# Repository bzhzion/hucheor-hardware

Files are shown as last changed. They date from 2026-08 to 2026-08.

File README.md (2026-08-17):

# Hucheor Hardware

Matériel et firmware pour **Hucheor**, une balise sonore pour les commerces de proximité qui
répond à la télécommande normalisée française utilisée par les personnes aveugles et malvoyantes
(NF S32-002, 868,3 MHz).

"Hucheor" est un mot de vieux français pour "celui qui appelle, qui guide".

Ce dépôt contient tout ce qui est destiné à être librement partagé et auto-constructible :

- `firmware/` : firmware ESP32 (décodage radio, lecture audio, configuration WiFi)
- `hardware/` : schémas KiCad et fichiers Gerber du circuit imprimé
- `enclosure/` : fichiers d'impression 3D du boîtier (STL)
- `docs/` : captures d'écran et maquettes HTML autonomes de l'interface de configuration (pour
  prévisualiser/tester les pages web sans flasher de matériel réel, voir
  [Interface de configuration](#interface-de-configuration) plus bas)

Le projet global (contexte métier, déploiement, site web) vit dans un dépôt privé séparé. Celui-ci
est la partie publique, en accès libre : n'importe qui peut consulter ces fichiers, les étudier, et
construire un exemplaire pour son usage strictement personnel. Voir [NOTICE.md](NOTICE.md) pour ce
que ça permet exactement (et ce que ça ne permet pas) : ce n'est **pas** une licence open source au
sens OSI, et la fabrication pour un tiers (même gratuite, même associative) est exclue.

## État

**Firmware v1 en développement actif.** L'essentiel de la partie logicielle qui ne dépend pas
d'avoir du matériel physique en main est implémenté et testé (lecture audio, planification,
synchronisation de l'horloge, réseau, interface de configuration, CI). Ce qui manque encore : le
décodage radio NF S32-002 lui-même (bloqué sur la capture d'un signal réel, voir
[Approche](#approche)) et le prototype physique lui-même.

| Domaine | État |
|---|---|
| Réception radio (CC1101 @ 868,3 MHz) | Initialisation + capture brute des fronts uniquement. La reconnaissance de trame (`matchesNfS32002Frame()`) renvoie toujours `false` pour l'instant : volontairement laissé non implémenté tant qu'une vraie capture RTL-SDR n'est pas disponible, voir plus bas. |
| Lecture audio | Fait. WAV (16 bits mono/stéréo) depuis LittleFS via I2S, voir [Lecture audio](#lecture-audio). |
| Planification des horaires d'ouverture | Fait. Modèles saisonniers + plages de semaines, voir [Planification](#planification-horaires-saisonniers). |
| Synchronisation de l'horloge | Fait. Trois sources indépendantes (DCF77, téléphone, NTP), voir [Synchronisation de l'horloge](#synchronisation-de-lhorloge). |
| Réseau (modes point d'accès / station) | Fait. Repli automatique, mDNS, serveur NTP configurable, voir [Modes réseau](#modes-réseau). |
| Interface web de configuration | Fait. Voir [Interface de configuration](#interface-de-configuration). |
| Sécurité | Audité, correctifs appliqués, voir [Sécurité](#sécurité). |
| CI | Build du firmware à chaque push + vérification hebdomadaire des dépendances, voir [Intégration continue](#intégration-continue). |
| Matériel / boîtier | Pas commencé, en attente d'un prototype firmware validé d'abord. |

## Comment ça marche

1. Une personne aveugle ou malvoyante a sur elle la télécommande NF S32-002 déjà distribuée à
   l'échelle nationale (la même que celle utilisée pour les feux piétons sonores et les bâtiments
   publics). Rien de nouveau à transporter.
2. Elle la pointe vers un commerce équipé d'une balise Hucheor et appuie sur le bouton, exactement
   comme elle le ferait devant la balise sonore d'un bâtiment public.
3. La balise (ESP32 + module radio CC1101) capte le signal 868,3 MHz, le reconnaît comme une trame
   NF S32-002, et lit les horaires d'ouverture configurés du commerce pour l'instant présent.
4. Elle diffuse un court message enregistré sur un haut-parleur (ampli I2S MAX98357A) : le nom du
   commerce, et s'il est actuellement ouvert ou fermé.

Aucune application, aucun smartphone requis pour l'usage principal : la télécommande existante est
toute l'interface. Voir la [Feuille de route](#feuille-de-route) pour ce qu'une future application
compagnon ajouterait en plus.

## Lecture audio

`firmware/src/audio_player.{h,cpp}`. Joue des fichiers WAV 16 bits (mono ou stéréo, n'importe
quelle fréquence d'échantillonnage) stockés sur le système de fichiers LittleFS interne de l'ESP32,
via I2S. Le commerçant envoie deux fichiers WAV via l'interface de configuration : un joué quand le
commerce est ouvert, un quand il est fermé (voir
[Interface de configuration](#interface-de-configuration)). Si aucun des deux n'a jamais été
envoyé (ou si les horaires n'ont jamais été configurés), le firmware se rabat sur un
`/message.wav` générique unique plutôt que de rester silencieux.

Le parseur WAV analyse les chunks au lieu de supposer un en-tête fixe de 44 octets (gère les
fichiers avec des chunks `LIST`/`fact` supplémentaires avant `data`), et est durci contre les
fichiers malformés (voir [Sécurité](#sécurité)).

Aucune bibliothèque audio tierce n'est utilisée : le choix évident, ESP8266Audio, est sous licence
GPLv3, ce qui forcerait tout ce dépôt sous une licence copyleft incompatible avec
[la licence ci-dessous](#licence). Le parsing WAV et la lecture I2S sont implémentés directement
au-dessus du `driver/i2s.h` natif du core Arduino ESP32.

## Planification (horaires saisonniers)

`firmware/src/schedule.{h,cpp}`. Les horaires d'ouverture d'un commerce sont rarement les mêmes
toute l'année (horaires d'été, fermeture de Noël, etc.), donc la planification est construite
autour de **modèles**, pas d'un horaire hebdomadaire fixe unique :

- Jusqu'à **4 modèles nommés** (ex. "Standard", "Été", "Vacances de Noël"), chacun un horaire
  hebdomadaire complet sur 7 jours (activé/désactivé par jour, heure d'ouverture, heure de
  fermeture). Un jour peut aussi être une plage nocturne (ferme après minuit, ex. un bar ouvert de
  20h à 2h) : le firmware le détecte automatiquement quand l'heure de fermeture est antérieure à
  l'heure d'ouverture.
- Jusqu'à **12 plages de numéros de semaine ISO** (1-53), chacune assignée à l'un des 4 modèles.
  Une semaine sans plage correspondante se rabat sur le premier modèle. Exemple : semaines 1 à 26
  utilisent "Standard", semaines 27 à 35 utilisent "Été", semaines 36 à 53 utilisent "Standard" à
  nouveau.

Tout ça se modifie depuis le navigateur du téléphone via l'[interface de
configuration](#interface-de-configuration), pas besoin de reflasher pour changer les horaires.

**Sécurité par défaut** : juste après un démarrage à froid ou une coupure de courant, avant qu'une
source d'heure n'ait synchronisé, l'horloge système affiche une valeur proche de zéro
(1970-01-01). `isOpenNow()` refuse de répondre dans ce cas et annonce "fermé" plutôt que de deviner
avec assurance un statut arbitraire à partir d'une date bidon : "fermé" est la mauvaise réponse la
moins grave pour un visiteur aveugle que "ouvert".

## Synchronisation de l'horloge

Le firmware ne calcule jamais lui-même l'heure d'été/d'hiver (CET/CEST). Chaque source d'horloge
est responsable de résoudre le changement d'heure de son côté et de transmettre **l'heure locale
française de l'horloge murale**, encodée comme si c'était de l'UTC : `Schedule` la relit toujours
avec `gmtime_r()`, jamais `localtime_r()`, donc aucune règle de changement d'heure européenne n'est
codée en dur nulle part dans ce firmware (une règle qui pourrait changer : il y a eu de vraies
discussions européennes sur l'abolition pure et simple du changement d'heure saisonnier).

Trois sources indépendantes, n'importe quelle combinaison d'entre elles peut être présente :

- **DCF77** (`firmware/src/dcf77_clock.{h,cpp}`) : un module récepteur grandes ondes 77,5 kHz
  optionnel. Décode le signal horaire allemand DCF77 (également reçu partout en France), qui
  diffuse déjà l'heure locale équivalente française plus des drapeaux CEST/CET en direct : aucune
  conversion nécessaire, fonctionne sans aucune connexion internet.
- **Synchronisation par téléphone** : visiter l'interface de configuration (n'importe quelle page)
  envoie les champs de l'horloge murale locale du téléphone qui configure (déjà ajustés pour le
  changement d'heure par la base de données de fuseaux horaires du système d'exploitation,
  régulièrement mise à jour) à la balise, via un petit script inline.
- **NTP** : disponible uniquement en [mode station](#modes-réseau) (accès internet). Un serveur NTP
  configurable (par défaut `fr.pool.ntp.org`) fournit l'UTC vrai, que le firmware convertit en
  heure locale française exactement une fois par synchronisation (une règle `TZ` transitoire
  appliquée puis immédiatement retirée : jamais laissée configurée en permanence) et se
  resynchronise automatiquement toutes les 6 heures pour corriger la dérive de l'horloge.

## Modes réseau

`firmware/src/network.{h,cpp}`. Deux modes de connexion, permutables depuis la page `/wifi` de
l'interface de configuration :

- **Autonome (par défaut)** : la balise crée son propre point d'accès WiFi (`Hucheor-XXXX`, WPA2,
  un mot de passe généré une fois par appareil). Pas d'accès internet : s'appuie sur DCF77 et/ou la
  synchronisation par téléphone pour l'heure.
- **Station** : la balise rejoint plutôt le réseau WiFi propre du commerce. Plus facile à
  atteindre pour la configuration (le téléphone reste sur son réseau habituel), découvrable via
  mDNS (`hucheor-xxxx.local`, aucune dépendance supplémentaire : `ESPmDNS` est fourni avec le core
  Arduino ESP32), et obtient une synchronisation NTP automatique de l'heure puisqu'elle a
  désormais accès à internet.

Se rabat automatiquement sur le mode autonome si des identifiants station sont configurés mais que
la connexion échoue (mauvais mot de passe, WiFi du commerce en panne, hors de portée) : une erreur
de configuration ne peut jamais rendre l'appareil inaccessible.

Non bloquant et résilient par conception : une connexion station perdue est retentée
automatiquement (délai de 30s entre tentatives, ne sature jamais la radio), et les resynchronisations
NTP se font en arrière-plan sans jamais bloquer la réception radio ou la lecture audio. La seule
attente volontairement bloquante est la tentative de connexion WiFi initiale au démarrage
(jusqu'à 15s, avant que quoi que ce soit d'autre n'ait démarré).

## Interface de configuration

`firmware/src/config_server.{h,cpp}`. Un petit serveur HTTP embarqué (aucune ressource externe,
fonctionne entièrement hors ligne sur le point d'accès autonome) pour que le commerçant configure
la balise depuis le navigateur de n'importe quel téléphone : aucune application requise pour la
configuration. Protégé par HTTP Digest Auth (un code à 12 chiffres, généré une fois par appareil,
jamais envoyé en clair sur le réseau : voir [Sécurité](#sécurité)). Le pied de page de chaque page
affiche la version du firmware en cours d'exécution (voir [Versionnage](#versionnage)).

| Page | À quoi ça sert |
|---|---|
| `/` | Envoyer les messages WAV "ouvert" et "fermé" (2 Mo max chacun). |
| `/schedule` | Modifier les modèles d'horaires d'ouverture et leur assigner des plages de semaines, voir [Planification](#planification-horaires-saisonniers). |
| `/wifi` | Basculer entre mode autonome/station, définir les identifiants WiFi du commerce, configurer le serveur NTP. |

Captures d'écran (générées à partir des maquettes autonomes dans
[`docs/mockups/`](docs/mockups/), qui reproduisent le HTML réellement généré par le firmware
au caractère près : utiles pour prévisualiser un changement d'interface sans flasher un appareil
réel) :

<table>
<tr>
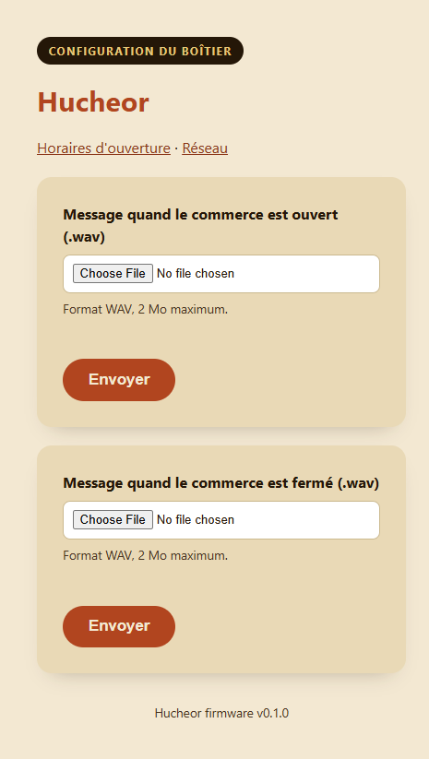
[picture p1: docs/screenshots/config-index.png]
Interface de configuration : page d'accueil avec les deux formulaires d'envoi WAV
<td></td>
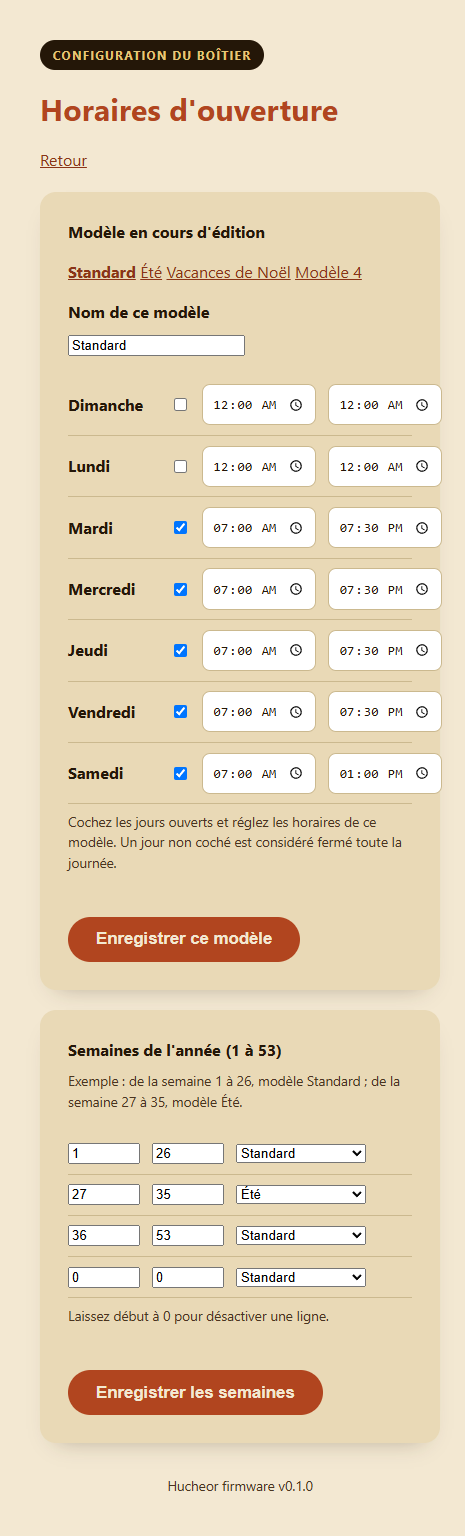
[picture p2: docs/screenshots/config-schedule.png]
Interface de configuration : éditeur des horaires d'ouverture
<td></td>
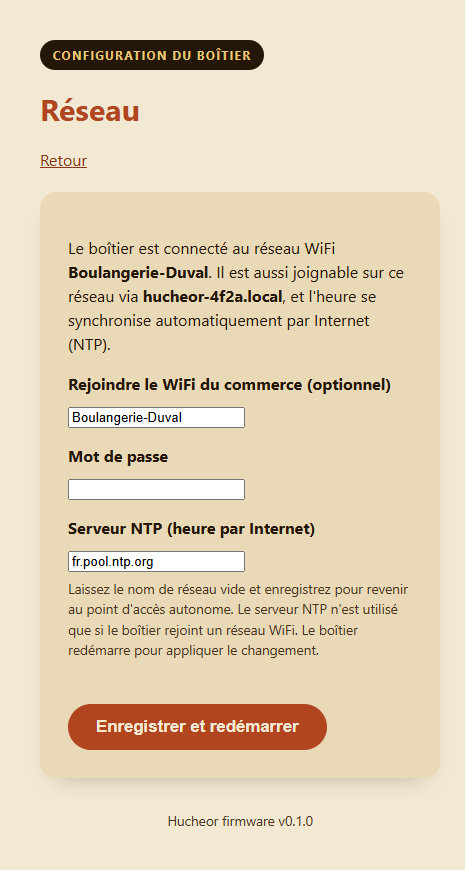
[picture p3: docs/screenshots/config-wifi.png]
Interface de configuration : page des paramètres réseau
<td></td>
</tr>
</table>

Même thème visuel que le site public ("Le Héraut" : parchemin/encre/terracotta), une pile de
polices système à la place des polices web personnalisées du site (inaccessibles depuis un point
d'accès hors ligne sans internet), et construit pour être utilisable : de vrais `<label>`, de
grandes cibles tactiles, des contours de focus visibles, aucun JavaScript en dehors du petit
script inline de synchronisation d'horloge.

### Parcours de première configuration

1. Flasher le firmware (voir [Compiler le firmware](#compiler-le-firmware)).
2. Allumer la balise. Elle démarre en mode autonome, en créant un réseau WiFi nommé
   `Hucheor-XXXX` (le suffixe exact vient de l'adresse MAC de l'appareil, affiché sur la console
   série au démarrage aux côtés des mots de passe WPA2 et de configuration).
3. Sur un téléphone, rejoindre ce réseau WiFi et ouvrir `http://hucheor-xxxx.local` (ou l'IP du
   point d'accès, `192.168.4.1`) dans un navigateur.
4. Se connecter avec les identifiants HTTP Digest affichés sur la console série au démarrage.
5. Envoyer les messages WAV "ouvert" et "fermé" sur la page d'accueil.
6. Aller sur **Horaires d'ouverture** et configurer au moins les horaires hebdomadaires du modèle
   "Standard". Ajouter des modèles saisonniers et des plages de semaines si besoin.
7. Optionnellement, aller sur **Réseau** et saisir les identifiants WiFi du commerce pour basculer
   en mode station (recommandé une fois la configuration faite : synchronisation automatique de
   l'heure par internet et accessibilité au quotidien plus simple via `hucheor-xxxx.local`).
8. Terminé : la balise répond désormais à toute télécommande NF S32-002 à portée.

## Sécurité

Audité selon une checklist adaptée à ce contexte embarqué ESP32 (pas un backend web classique),
centrée sur les deux nouvelles surfaces d'attaque : le serveur de configuration (traite des envois
et des identifiants non fiables) et le parseur WAV (traite du contenu de fichier non fiable).

**Corrigé :**
- Underflow entier dans le parseur du chunk `fmt ` d'un WAV (une taille de chunk malformée
  inférieure à 16 octets débordait en arithmétique non signée vers un offset `seek()` énorme) :
  désormais rejeté explicitement.
- La valeur de retour de `seek()` n'était jamais vérifiée, ce qui pouvait laisser un fichier WAV
  malformé faire tourner la boucle du parseur indéfiniment (déni de service) : interrompt
  désormais le parsing au moindre échec de `seek()`.
- Aucune limite de taille sur les envois : plafonné à 2 Mo par fichier, largement suffisant pour un
  message vocal court, les envois tronqués/corrompus sont supprimés plutôt que laissés comme
  message actif.
- `esp_random()` (utilisé pour générer les mots de passe WiFi et HTTP) était appelé avant
  l'activation de la radio WiFi, ce qui affaiblit son entropie selon la documentation même
  d'Espressif : réordonné pour que l'initialisation radio se fasse d'abord.
- Une seule écriture I2S en `portMAX_DELAY` sans timeout pouvait bloquer tout le firmware
  indéfiniment si l'ampli audio arrêtait de vider son tampon DMA (matériel déconnecté/défaillant) :
  remplacé par un timeout généreusement borné de 2 secondes, la lecture s'interrompt proprement au
  lieu de figer l'appareil.

**Par conception, pas une faille** : le serveur de configuration utilise HTTP Digest Auth (via le
challenge par défaut d'`ESPAsyncWebServer`), pas Basic : le mot de passe n'est jamais envoyé en
clair, même sur un réseau WiFi non chiffré. Le TLS complet a été envisagé et volontairement écarté :
pas de support HTTPS mature dans la bibliothèque de serveur web utilisée ici, un certificat
auto-signé afficherait un avertissement "non sécurisé" inquiétant aux commerçants non techniciens à
chaque visite, et le modèle de menace réaliste (un attaquant devrait déjà être sur le même réseau
WiFi que le commerce) ne justifie pas la complexité supplémentaire.

**Risque accepté** : les deux mots de passe de l'appareil (point d'accès WiFi + HTTP Digest) sont
un code numérique à 12 chiffres sans verrouillage après échecs répétés (10^12 combinaisons, et un
attaquant est déjà contraint à la proximité physique WiFi : pas un service exposé à internet).

## Intégration continue

Trois workflows GitHub Actions :
- **Build** (`.github/workflows/build-firmware.yml`) : compile le firmware à chaque push/PR qui
  touche `firmware/`.
- **Vérification des dépendances** (`.github/workflows/check-deps.yml`) : tourne chaque semaine
  (et à la demande), vérifie les paquets PlatformIO obsolètes, et ouvre/ferme automatiquement une
  issue GitHub selon le résultat.
- **Release** (`.github/workflows/release.yml`) : déclenché en poussant un tag `vX.Y.Z`. Compile
  le firmware avec cette version injectée (voir [Versionnage](#versionnage) plus bas) et publie
  une GitHub Release avec `firmware.bin`/`firmware.elf` compilés en pièces jointes.

## Versionnage

La version affichée en bas de chaque page de l'[interface de
configuration](#interface-de-configuration) vient du tag Git utilisé pour compiler ce firmware,
jamais une valeur codée en dur dans le code. `firmware/scripts/gen_version.py` (un script
pre-build PlatformIO) génère `firmware/include/version.h` à partir de la variable d'environnement
`FIRMWARE_VERSION`, fixée au tag poussé par le workflow de release ci-dessus : se rabat sur
`"dev"` pour tout build qui n'est pas déclenché par un tag (builds locaux, vérifications CI
classiques de build/PR), donc il est toujours évident si un firmware donné vient d'une release
officielle. Même logique que les applications mobiles de cet écosystème (voir `docs/mobile-app-releases.md`
du dépôt admin) : la version est injectée au moment du build, jamais committée.

Pour publier une release : `git tag vX.Y.Z && git push origin vX.Y.Z`.

## Compiler le firmware

Nécessite [PlatformIO](https://platformio.org/). Depuis `firmware/` :

```sh
pio run            # compiler
pio run -t upload  # flasher un ESP32 connecté
```

## Feuille de route

- **v1 (MVP, en cours)** : réception NF S32-002 (868,3 MHz) + lecture audio par haut-parleur. Voir
  le tableau [État](#état) plus haut pour le détail de ce qui est fait.
- **v2 (Bluetooth LE Audio / Auracast)** : diffuser le message directement dans les aides auditives
  et écouteurs compatibles, en plus du haut-parleur. Aucune balise en accès libre ne combine
  aujourd'hui réception 868,3 MHz et Auracast. Pas une fonctionnalité ESP32 seul : l'Auracast
  complet (codec LC3, Broadcast Isochronous Streams, interopérabilité certifiée) nécessite un
  coprocesseur dédié, probablement un Nordic nRF5340 (module candidat : Aurawave AW100), qui
  dialogue avec l'ESP32 via UART/SPI.
- **v3 (application mobile compagnon)** : React Native / Expo (iOS + Android), cohérent avec le
  reste des applications mobiles de l'écosystème. Déclenchement BLE des balises, réception
  Auracast, annuaire des commerces équipés, mode navigation GPS. Reste compatible avec la
  télécommande physique NF S32-002 existante (l'application la complète, ne la remplace jamais).
- **v4 (écosystème)** : interface de gestion pour les commerçants, cartographie des balises basée
  sur OpenStreetMap, intégration annuaire.

La priorité reste de finir la v1 (vraie capture radio + un prototype câblé) avant de démarrer la
v2.

## Accessibilité

Ce projet existe pour les personnes aveugles et malvoyantes. Toute interface construite ici
(interface web de configuration du firmware, future application compagnon) doit viser **WCAG 2.2
AA au minimum** dès le premier jet : contraste fort, tailles de police généreuses, aucun texte
porté uniquement par une image, navigation clavier complète, attributs ARIA corrects, respect des
préférences de mouvement réduit. Ce n'est pas optionnel sur ce projet.

## Approche

Le firmware de Hucheor est écrit indépendamment, à partir de zéro, en utilisant uniquement les
paramètres radio publiquement documentés de la norme NF S32-002 (868,3 MHz, OOK) : aucun code
emprunté.

Le décodage de trame radio est volontairement laissé non implémenté (`matchesNfS32002Frame()`
renvoie toujours `false`) tant qu'un signal réel n'a pas été capturé au RTL-SDR depuis une vraie
télécommande NF S32-002 : aucune constante de timing devinée ou empruntée à un autre projet.

## Licence

**BREIZHZION Personal Use License (BZ-1.1)**. Voir [NOTICE.md](NOTICE.md) pour ce que ça veut dire
en pratique, et [LICENSE.md](LICENSE.md) pour le texte légal complet. En résumé : lisez, étudiez,
modifiez pour votre usage personnel, et construisez-en un seul exemplaire pour vous-même. Vous ne
pouvez pas en fabriquer pour un tiers (même gratuitement, même associatif), ni distribuer une
version modifiée. Seule BREIZHZION (ou un tiers avec une licence commerciale écrite) peut fabriquer
pour autrui, vendre, installer ou fournir un service basé sur ce projet.

Ce n'est volontairement **pas une licence open source au sens OSI** : ce projet doit être décrit
comme en accès libre, pas open source.

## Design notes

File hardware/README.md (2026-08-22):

# Matériel

Les schémas KiCad et fichiers Gerber du circuit imprimé de la balise Hucheor viendront ici.

Le premier prototype physique est encore en cours de câblage sur plaque d'essai (ESP32 + CC1101 +
MAX98357A + DCF77). Le PCB final viendra une fois ce prototype validé.

[`WIRING.md`](WIRING.md) documente le câblage précis à suivre (nomenclature, architecture
d'alimentation, brochage broche par broche) - identique à ce qu'utilise le firmware
(`firmware/src/main.cpp`), pour que la plaque d'essai et le schéma KiCad partent de la même base
sans rien deviner.

## `hucheor.kicad_sch` : généré par script, ERC vérifiée

Ce schéma est généré par `generate_schematic.py` (bibliothèque Python `kiutils`) à partir du
câblage documenté dans `WIRING.md`. KiCad 10 est maintenant installé sur la machine qui l'a produit
: le fichier a été **rechargé avec succès et passé à l'ERC via `kicad-cli sch erc`**, pas seulement
relu par la bibliothèque qui l'a écrit.

**22 avertissements ERC restants, tous attendus** (voir la sortie de `kicad-cli sch erc` pour le
détail) :
- `power_pin_not_driven` / `ground_pin_not_ground` : les connexions passent par des labels de net
  (`+5V`, `GND`, `+3V3`) plutôt que par de vrais symboles de flag d'alimentation KiCad (`power:GND`,
  `power:+3V3`...) - à ajouter dans l'éditeur si on veut faire taire ces avertissements, purement
  cosmétique.
- `lib_symbol_issues` (bibliothèque vide `''`) : les 6 symboles (ESP32, CC1101, MAX98357A, DCF77,
  haut-parleur, connecteur d'alimentation) sont générés sur mesure (aucun symbole officiel KiCad
  pour ces breakouts hobbyistes) et ne sont pas encore enregistrés dans une table de bibliothèque
  de projet (`sym-lib-table`) - sans conséquence pour la lecture/l'ERC, à faire si on veut les
  réutiliser proprement dans d'autres projets KiCad.
- `endpoint_off_grid` : imprécision flottante mineure sur les coordonnées de broches
  (ex. `15.239999999999998` au lieu de `15.24`), cosmétique.

Aucune empreinte (footprint) assignée pour l'instant, normal à ce stade - à faire une fois les
breakouts précis choisis.

**Pour vérifier ou régénérer** :
```
# Verifier (KiCad installe)
kicad-cli sch erc --severity-all hardware/hucheor.kicad_sch

# Regenerer apres une modification de WIRING.md
cd hardware
python -m venv .kicad-venv        # une fois
.kicad-venv/Scripts/pip install kiutils
.kicad-venv/Scripts/python generate_schematic.py
```

Historique de mise au point (utile si `generate_schematic.py` est modifié un jour) : la première
version chargeait dans `kiutils` mais **échouait au chargement dans KiCad 10** avec un message
générique `Failed to load schematic`, sans plus de détail. Cause trouvée par bissection contre un
vrai fichier KiCad round-trippé par `kiutils` (qui, lui, se rechargeait sans erreur) : les broches
doivent être portées par des **sous-unités imbriquées** du symbole (unité 0 = dessin, unité 1 =
broches - convention utilisée par tous les symboles KiCad officiels, y compris les plus simples
comme `Device:R`), pas directement sur le symbole parent ; et la position de chaque propriété
(`Reference`, `Value`...) doit avoir un angle explicite (`0` si non tourné), sinon KiCad 10 refuse
de charger l'instance placée alors même que `kiutils` l'écrit et la relit sans broncher.

Sous licence BREIZHZION Personal Use License (BZ-1.1), voir `LICENSE.md`/`NOTICE.md` à la racine
du dépôt.

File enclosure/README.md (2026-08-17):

# Boîtier

Les fichiers d'impression 3D (STL) du boîtier de la balise Hucheor viendront ici, une fois le PCB
et la disposition des composants suffisamment avancés pour concevoir autour.

Objectif : IP65 pour une installation extérieure en devanture, imprimable sur une Bambu Lab P1S.

Sous licence BREIZHZION Personal Use License (BZ-1.1), voir `LICENSE.md`/`NOTICE.md` à la racine du
dépôt.

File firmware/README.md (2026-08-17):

# Firmware

Firmware ESP32 pour la balise Hucheor, construit avec [PlatformIO](https://platformio.org/). Voir
le [README à la racine du dépôt](../README.md) pour le parcours complet (installation, posture
sécurité, CI), ce fichier reste un résumé court par module.

## État

- Radio : initialisation et capture brute des fronts uniquement. Le décodage de trame NF S32-002
  n'est **pas implémenté** pour l'instant : voir `src/main.cpp` pour le détail du pourquoi (ça
  nécessite des données de timing réelles issues de notre propre capture RTL-SDR, pas des valeurs
  devinées ou empruntées).
- Audio (`audio_player.h`/`.cpp`) : joue un fichier WAV PCM 16 bits mono/stéréo depuis LittleFS via
  I2S. Uniquement le driver I2S natif de l'ESP32, aucune bibliothèque audio tierce (le choix
  évident, ESP8266Audio, est en GPLv3 : incompatible avec la licence BZ-1.1 de ce dépôt).
- Réseau (`network.h`/`.cpp`) : deux modes de connexion. Autonome (par défaut) crée son propre
  point d'accès WiFi (`Hucheor-XXXX`) ; station rejoint plutôt le WiFi propre du commerce, avec
  repli automatique sur le mode autonome en cas d'échec. Le mode station s'annonce via mDNS
  (`hucheor-xxxx.local`) pour qu'une future application compagnon puisse le découvrir, et
  synchronise l'heure via NTP puisqu'il a accès à internet.
- Serveur de configuration (`config_server.h`/`.cpp`) : pages HTML accessibles (de vrais
  `<label>`, contours de focus visibles, seul JS de la page : un petit script de synchronisation
  d'horloge - le seuil WCAG 2.2 AA est requis sur tout le projet) pour envoyer les messages
  ouvert/fermé séparément, modifier les horaires d'ouverture, et changer de mode WiFi.
- Planification (`schedule.h`/`.cpp`) : jusqu'à 4 modèles hebdomadaires saisonniers (ex.
  "Standard", "Été"), et jusqu'à 12 plages de semaines ISO (1-53) assignant quel modèle s'applique
  quand.
- Horloge : trois sources indépendantes, aucune ne nécessite de règle de changement d'heure codée
  en dur dans ce firmware (voir le commentaire en tête de `schedule.h`) - l'horloge du téléphone
  (synchronisée automatiquement à chaque fois que le commerçant ouvre la page de configuration), un
  **récepteur grandes ondes DCF77** (`dcf77_clock.h`/`.cpp`, une seule broche GPIO, écrit depuis
  zéro à partir de la spécification publique du télégramme DCF77, sur le même principe que le
  travail NF S32-002 propre à ce projet), et NTP (disponible uniquement en mode station).
- Pas encore câblé : le déclenchement décodage de trame -> lecture audio existe dans `main.cpp`
  mais appelle un décodeur qui renvoie toujours `false` pour l'instant.

## Compilation

```
cd firmware
pio run
```

## Matériel (prévu)

- MCU : ESP32 (S3 ou C3 de préférence)
- Radio : CC1101 (SPI), 868,3 MHz OOK
- Audio : MAX98357A (I2S) + haut-parleur
- Horloge : module récepteur DCF77 (~5-10 EUR, une broche GPIO), optionnel mais recommandé
- Câblage : pas encore finalisé, voir les commentaires de broches dans `src/main.cpp` ; sera mis à
  jour une fois le premier prototype réellement câblé et testé.

## Licence

Le code de ce dossier est sous licence BREIZHZION Personal Use License (BZ-1.1) (voir
`LICENSE.md`/`NOTICE.md` à la racine du dépôt). Les dépendances tierces récupérées via PlatformIO
gardent leur propre licence :
- `CC1101-ESP-Arduino` : MIT
- `ESPAsyncWebServer` / `AsyncTCP` : LGPL-3.0 (copyleft faible, sûr en dépendance : contrairement à
  GPL/AGPL, LGPL autorise explicitement la liaison depuis du code sous une licence différente)
- LittleFS : fourni avec le core Arduino ESP32 lui-même, pas une dépendance séparée

Écarté : `ESP8266Audio` (GPLv3 : forcerait tout ce firmware sous GPL, incompatible avec BZ-1.1).

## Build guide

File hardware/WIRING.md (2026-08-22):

# Câblage de référence (avant schéma KiCad)

Ce document liste précisément quoi brancher où, pour que le premier prototype sur plaque d'essai
et le futur schéma KiCad partent de la même base, sans rien deviner à l'un ou l'autre bout. Les
numéros de broche ESP32 correspondent exactement à ceux déjà utilisés dans le firmware
(`firmware/src/main.cpp`), pas de valeur inventée ici.

## Nomenclature (BOM)

| Réf. | Composant | Rôle | Alimentation | Remarque |
|---|---|---|---|---|
| U1 | ESP32-WROOM-32 DevKit (30 ou 38 broches) | MCU | 5V via USB/VIN, régule en 3,3V en interne | N'importe quel clone générique "ESP32 DevKitC" convient |
| U2 | Module CC1101 868 MHz (breakout SPI) | Réception radio NF S32-002 | 3,3V (broche 3V3 de U1) | Antenne à ressort souvent déjà soudée sur le module |
| U3 | Module ampli I2S MAX98357A (breakout) | Amplification audio | 5V (rail USB, pas via U1) | Sortie jusqu'à 3W sous 4Ω |
| U4 | Module récepteur DCF77 77,5 kHz | Synchro horaire autonome | 3,3V (broche 3V3 de U1) | Optionnel mais recommandé |
| SP1 | Haut-parleur 4Ω, 3-5W | Diffusion du message | - | Connecteur JST-PH 2 broches conseillé |
| J1 | Connecteur USB-C ou Micro-USB (souvent déjà sur U1) | Alimentation 5V | - | Alimentation secteur 5V/1A minimum une fois en devanture |

## Architecture d'alimentation

Tout part du rail **5V** (USB) :
- U1 (ESP32) régule ce 5V en 3,3V en interne via son propre régulateur embarqué, et expose cette
  3,3V régulée sur sa broche `3V3`.
- U2 (CC1101) et U4 (DCF77) sont alimentés depuis cette broche `3V3` de U1 : leur consommation est
  faible (quelques dizaines de mA), largement dans la marge du régulateur embarqué d'un DevKit
  standard.
- U3 (MAX98357A) est alimenté **directement depuis le rail 5V**, pas depuis la 3,3V de U1 : la
  puissance de sortie audio (jusqu'à 3W) dépend directement de la tension d'alimentation de
  l'ampli, le faire passer par le régulateur 3,3V de l'ESP32 le priverait de la moitié de sa
  puissance et solliciterait inutilement ce régulateur.

Ne jamais alimenter U3 depuis la broche `3V3` de U1 pour cette raison.

## Brochage détaillé

### U2 : module CC1101 (868 MHz)

| Broche module CC1101 | Connecté à (U1 ESP32) | Signal |
|---|---|---|
| VCC | 3V3 | Alimentation 3,3V |
| GND | GND | Masse |
| SCK | GPIO18 | Horloge SPI (VSPI) |
| MISO | GPIO19 | Données SPI entrantes |
| MOSI | GPIO23 | Données SPI sortantes |
| CSN | GPIO5 | Chip select SPI |
| GDO0 | GPIO4 | Sortie données radio, lue par interruption |
| GDO2 | non connecté | Non utilisé par ce firmware |

GPIO18/19/23/5 correspondent au bus SPI matériel par défaut de l'ESP32 (VSPI) : aucun autre
périphérique SPI n'est utilisé, pas de partage de bus à gérer.

### U3 : module ampli I2S MAX98357A

| Broche module MAX98357A | Connecté à | Signal |
|---|---|---|
| VIN | Rail 5V (pas U1/3V3, voir ci-dessus) | Alimentation |
| GND | GND | Masse |
| BCLK | GPIO26 | Horloge de bit I2S |
| LRC | GPIO25 | Word select (gauche/droite) I2S |
| DIN | GPIO27 | Données audio I2S |
| SD | Non connecté | Laissé flottant = ampli actif, gain par défaut (tiré en interne par le module) |
| GAIN | Non connecté | Gain par défaut (9 dB), ajustable plus tard si besoin (voir datasheet MAX98357A) |
| + / - (sortie HP) | SP1 (haut-parleur) | Sortie audio différentielle vers le haut-parleur |

### U4 : module récepteur DCF77

| Broche module DCF77 | Connecté à (U1 ESP32) | Signal |
|---|---|---|
| VCC | 3V3 | Alimentation 3,3V |
| GND | GND | Masse |
| OUT (parfois nommée "T" ou "DATA") | GPIO32 | Signal démodulé, lu par interruption sur front |
| PON (si présente) | Non connectée | Laissée flottante = module toujours actif sur la plupart des breakouts courants |

Le brochage exact varie légèrement selon le fabricant du module DCF77 (souvent 3 broches
VCC/GND/OUT, parfois une 4e broche d'activation) : vérifier la sérigraphie du module reçu avant de
câbler, certains inversent VCC/GND par rapport à d'autres.

## Antennes

- **CC1101** : antenne à ressort (souvent déjà soudée sur le module) suffit pour la portée visée
  (devanture de commerce, quelques mètres). Pas besoin d'antenne externe/déportée pour le
  prototype.
- **DCF77** : antenne ferrite généralement déjà intégrée au module, orientation sensible (à tester
  sur place, la réception grandes ondes est directionnelle).

## Notes pour le passage au schéma KiCad

- Utiliser les symboles génériques "ESP32-WROOM-32" et "MAX98357A" déjà présents dans les
  bibliothèques KiCad standard (`RF_Module`, `Amplifier_Audio`) plutôt qu'un symbole de DevKit
  complet, si le PCB final intègre le module ESP32 directement plutôt qu'un DevKit entier.
- Prévoir un connecteur JST-PH 2 broches pour SP1 et pour l'alimentation 5V (J1), plus robuste
  qu'un simple bornier à vis pour un appareil qui sera manipulé/installé.
- Découpler chaque alimentation (100nF + 10µF en parallèle, au plus près de chaque module) : pas
  fait sur les breakouts du commerce, à ajouter explicitement sur le PCB final.

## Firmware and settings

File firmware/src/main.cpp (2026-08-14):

// Hucheor beacon firmware skeleton (ESP32 + CC1101 @ 868.3 MHz OOK).
//
// This is written from scratch: only the publicly documented radio
// parameters of the NF S32-002 standard (868.3 MHz, OOK) are used, no
// borrowed code or timing constants.
//
// Status: radio init + raw edge capture only. The actual NF S32-002 frame
// matching is NOT implemented yet - it needs real timing data from our own
// RTL-SDR capture (see project roadmap) before it can be written correctly.
// Do not guess or borrow timing constants from other projects here.

#include <Arduino.h>
#include <CC1101_ESP_Arduino.h>

#include "audio_player.h"
#include "config_server.h"
#include "dcf77_clock.h"
#include "network.h"
#include "schedule.h"

// Wiring: to be confirmed once the first prototype is actually built.
static const int PIN_SPI_SCK = 18;
static const int PIN_SPI_MISO = 19;
static const int PIN_SPI_MOSI = 23;
static const int PIN_SPI_CS = 5;
static const int PIN_RADIO_GDO0 = 4; // CC1101 data output, read on edge interrupt

static const int PIN_I2S_BCK = 26;
static const int PIN_I2S_WS = 25;
static const int PIN_I2S_DATA = 27;

static const int PIN_DCF77 = 32; // optional: DCF77 receiver module output

CC1101 radio(PIN_SPI_SCK, PIN_SPI_MISO, PIN_SPI_MOSI, PIN_SPI_CS, PIN_RADIO_GDO0, PIN_RADIO_GDO0);

static const size_t EDGE_BUFFER_SIZE = 800;
volatile uint32_t edgeIntervalsUs[EDGE_BUFFER_SIZE];
volatile size_t edgeCount = 0;
volatile bool bufferReady = false;

// ISR: only record timings, never do Serial/logging or anything blocking here.
void IRAM_ATTR onRadioEdge() {
  static uint32_t lastEdgeUs = 0;
  uint32_t now = micros();
  uint32_t delta = now - lastEdgeUs;
  lastEdgeUs = now;

  if (edgeCount < EDGE_BUFFER_SIZE) {
    edgeIntervalsUs[edgeCount++] = delta;
  }
  if (edgeCount >= EDGE_BUFFER_SIZE) {
    bufferReady = true;
  }
}

// TODO(hucheor): implement once we have our own NF S32-002 capture.
// Must not assume a hardcoded timing table - derive the real preamble/bit
// encoding from our own RTL-SDR recording first.
bool matchesNfS32002Frame(const volatile uint32_t *intervalsUs, size_t count) {
  (void)intervalsUs;
  (void)count;
  return false;
}

void setup() {
  Serial.begin(115200);
  delay(200);

  // Deliberately no setenv("TZ", ...) here: every time source (DCF77,
  // phone-clock sync, NTP once Network is in station mode) hands
  // Schedule::setCurrentTime() already-correct French local wall-clock
  // time, encoded as if it were UTC. Schedule reads it back with gmtime_r(),
  // never localtime_r() - no CEST/CET rule is hardcoded in this firmware.
  // See schedule.h for the full reasoning (a hardcoded EU DST rule would go
  // silently wrong if that legislation ever changes without a matching
  // firmware update).

  radio.init();
  radio.setMHZ(868.3);
  radio.setModulation(ASK_OOK);
  radio.setRx();

  attachInterrupt(digitalPinToInterrupt(PIN_RADIO_GDO0), onRadioEdge, CHANGE);

  if (!AudioPlayer::begin(PIN_I2S_BCK, PIN_I2S_WS, PIN_I2S_DATA)) {
    Serial.println("Hucheor: audio player init failed");
  }

  Schedule::begin();
  Network::begin(); // decides standalone AP vs joining the shop's WiFi, see network.h
  ConfigServer::begin();
  Dcf77Clock::begin(PIN_DCF77);

  Serial.println("Hucheor: listening on 868.3 MHz (no frame decoding yet)");
}

void loop() {
  Network::poll(); // non-blocking: station reconnect + periodic NTP resync, see network.h

  if (Dcf77Clock::poll()) {
    Serial.println("Hucheor: clock synced from DCF77");
  }

  if (bufferReady) {
    noInterrupts();
    bool matched = matchesNfS32002Frame(edgeIntervalsUs, edgeCount);
    edgeCount = 0;
    bufferReady = false;
    interrupts();

    if (matched) {
      Serial.println("Remote detected");
      const char *path = Schedule::isOpenNow() ? "/message_open.wav" : "/message_closed.wav";
      if (!AudioPlayer::playWavFile(path)) {
        // Shopkeeper only uploaded one generic message (or the schedule was
        // never configured): fall back to it rather than staying silent.
        AudioPlayer::playWavFile("/message.wav");
      }
    }
  }
}

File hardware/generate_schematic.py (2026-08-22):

#!/usr/bin/env python3
"""Genere un premier jet de schema KiCad (hucheor.kicad_sch) a partir du
cablage documente dans WIRING.md.

IMPORTANT : genere sans avoir KiCad installe sur cette machine, donc jamais
verifie visuellement ni passe a l'ERC. A ouvrir dans KiCad et verifier avant
de faire confiance a ce fichier pour quoi que ce soit de reel - voir la note
en tete de hardware/README.md.
"""

import uuid as uuid_mod

from kiutils.schematic import Schematic, SchematicSymbol, Property, LocalLabel, NoConnect
from kiutils.items.common import Position, Effects, Font
from kiutils.items.schitems import SymbolProjectInstance, SymbolProjectPath
from kiutils.symbol import Symbol, SymbolPin, SyRect

PROJECT_NAME = "hucheor"
PIN_LEN = 2.54
ROW = 2.54


def new_uuid():
    return str(uuid_mod.uuid4())


def make_module_symbol(entry_name, value, left_pins, right_pins, is_power=False):
    """left_pins/right_pins: liste de (name, number, electrical_type).

    Suit la convention reelle de KiCad (verifiee sur des symboles officiels
    types "Device:R") : le symbole parent ne porte que les proprietes, deux
    sous-unites imbriquees portent le dessin (unite 0, partagee) et les
    broches (unite 1). Un symbole avec les broches posees directement sur le
    parent (sans ces sous-unites) est syntaxiquement valide pour kiutils mais
    rejete par KiCad des qu'il faut resoudre les broches d'une instance
    placee - trouve par diff contre un vrai fichier KiCad round-trippe."""
    n_left, n_right = len(left_pins), len(right_pins)
    n_max = max(n_left, n_right, 1)
    half_height = (n_max - 1) * ROW / 2 + ROW
    half_width = 12.7  # assez large pour les noms de broche les plus longs

    symbol = Symbol.create_new(id=entry_name, reference="U", value=value)
    symbol.isPower = is_power
    symbol.pinNames = True
    symbol.pinNumbers = True

    unit_graphics = Symbol(entryName=entry_name, unitId=0, styleId=1)
    unit_pins = Symbol(entryName=entry_name, unitId=1, styleId=1)

    unit_graphics.graphicItems.append(SyRect(
        start=Position(X=-half_width, Y=half_height),
        end=Position(X=half_width, Y=-half_height),
    ))

    def add_side(pins, side):
        count = len(pins)
        top_y = (count - 1) * ROW / 2
        for i, (name, number, etype) in enumerate(pins):
            y = top_y - i * ROW
            if side == "L":
                x = -half_width - PIN_LEN
                angle = 180
            else:
                x = half_width + PIN_LEN
                angle = 0
            unit_pins.pins.append(SymbolPin(
                electricalType=etype,
                position=Position(X=x, Y=y, angle=angle),
                length=PIN_LEN,
                name=name,
                number=str(number),
            ))

    add_side(left_pins, "L")
    add_side(right_pins, "R")
    symbol.units = [unit_graphics, unit_pins]
    return symbol


def all_pins(symbol_def):
    """Reunit les broches, qu'elles soient (par erreur) sur le symbole
    parent ou (cas normal) sur une sous-unite."""
    pins = list(symbol_def.pins)
    for unit in symbol_def.units:
        pins.extend(unit.pins)
    return pins


def place(schematic, symbol_def, ref, value, x, y, pin_side_map):
    """Place une instance du symbole sur la feuille, renvoie un dict
    {pin_name: (abs_x, abs_y)} pour poser les labels de net ensuite."""
    inst = SchematicSymbol()
    inst.libId = symbol_def.libId
    inst.position = Position(X=x, Y=y, angle=0)
    inst.unit = 1
    inst.inBom = True
    inst.onBoard = True
    inst.uuid = new_uuid()
    # L'angle doit etre fixe explicitement (meme a 0) sur la position de
    # chaque propriete ET du symbole lui-meme (voir Position ci-dessus) :
    # kiutils omet le 3e nombre de "(at X Y)" quand angle=None, ce que
    # KiCad 10 refuse de charger pour une instance placee (verifie par
    # bissection contre un vrai fichier round-trippe par kiutils).
    inst.properties = [
        Property(key="Reference", value=ref, id=0,
                  position=Position(X=x, Y=y - 15, angle=0), effects=Effects(font=Font(width=1.27, height=1.27))),
        Property(key="Value", value=value, id=1,
                  position=Position(X=x, Y=y - 12.5, angle=0), effects=Effects(font=Font(width=1.27, height=1.27))),
    ]
    inst.instances = [SymbolProjectInstance(
        name=PROJECT_NAME,
        paths=[SymbolProjectPath(sheetInstancePath="/", reference=ref, unit=1)],
    )]

    pin_positions = {}
    for pin in all_pins(symbol_def):
        inst.pins[pin.number] = new_uuid()
        pin_positions[pin.name] = (x + pin.position.X, y + pin.position.Y)

    schematic.schematicSymbols.append(inst)
    return pin_positions


def add_net_label(schematic, text, pos, angle=0):
    schematic.labels.append(LocalLabel(
        text=text,
        position=Position(X=pos[0], Y=pos[1], angle=angle),
        effects=Effects(font=Font(width=1.27, height=1.27)),
    ))


def add_no_connect(schematic, pos):
    schematic.noConnects.append(NoConnect(position=Position(X=pos[0], Y=pos[1])))
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

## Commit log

2026-08-14 feat: lecture audio I2S (WAV/LittleFS) + serveur de config WiFi, etapes 5 et 6
2026-08-14 docs: firmware - statut audio/config server, licences des dependances
2026-08-14 ci: se passer de actions/setup-python (incompatible avec Debian 13 bare-metal), utiliser le python3 systeme
2026-08-14 ci: utiliser un venv pour PlatformIO, portable quelle que soit la version de pip
2026-08-14 feat: page de config embarquee cohérente avec l'identite du site (carte, palette Le Heraut), gestion propre du refus si upload trop volumineux
2026-08-14 feat: gestion des horaires ouvert/ferme (etape 7), messages open/closed distincts, sync heure via navigateur
2026-08-14 chore: gitignore pour les artefacts de build PlatformIO
2026-08-14 feat: modeles horaires saisonniers par semaine (1-53) + module recepteur DCF77, correctif fuseau horaire
    [main.cpp]
2026-08-14 docs: firmware - modeles saisonniers, DCF77, correctif fuseau horaire
2026-08-14 feat: mode WiFi standalone/station avec decouverte mDNS et sync NTP, correctif conception heure d'ete
    [main.cpp, network.cpp]
2026-08-14 feat: serveur NTP configurable via la page reseau
2026-08-14 fix: resilience reseau non-bloquante (reconnexion WiFi + resync NTP periodique)
    [main.cpp, network.cpp]
2026-08-14 fix: audit complet des appels bloquants, resilience post-redemarrage
    - audio_player: remplace portMAX_DELAY par un timeout borne (2s) sur
    i2s_write, pour ne jamais bloquer le firmware si le DMA I2S ne se
    vide plus (ampli deconnecte/en panne)
    - schedule: isOpenNow() refuse desormais de repondre tant que l'horloge
    systeme n'a pas ete synchronisee (post-boot/coupure electrique,
    epoch proche de zero) - annonce "ferme" plutot que de deviner un
    statut base sur une date bidon
    - revue de tous les delay()/while()/portMAX_DELAY du firmware : le
    reste est deja borne ou strictement limite au demarrage (connexion
    WiFi initiale, flush HTTP avant redemarrage)
    [audio_player.cpp]
2026-08-14 ci: ajoute un check hebdomadaire des dependances firmware
    Cron du lundi + declenchement manuel, ouvre/ferme automatiquement une
    issue GitHub selon le resultat de pio pkg outdated (idempotent).
2026-08-14 docs: documentation complete du repo public + tutoriel avec captures
    - README racine reecrit : etat reel de chaque fonctionnalite (audio,
    planning saisonnier, synchro horloge, reseau AP/station, UI de
    config, securite, CI), tutoriel de premiere config pas a pas,
    captures d'ecran des 3 pages web embarquees
    - docs/mockups/ : versions HTML autonomes des pages de config,
    identiques au rendu reel du firmware, pour previsualiser sans
    flasher de materiel (utilisees pour generer les captures)
    - roadmap v3 : React Native/Expo au lieu de Flutter, coherent avec
    le reste de l'ecosysteme des apps mobiles
    - corrige l'absence totale d'accents dans le texte francais affiche
    aux utilisateurs (c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
    [main.cpp]
2026-08-14 feat: versionne le firmware via tag Git, affiche dans le pied de page
    Meme pattern que les apps mobiles (voir admin repo
    docs/mobile-app-releases.md) : firmware/scripts/gen_version.py genere
    firmware/include/version.h a partir de FIRMWARE_VERSION (jamais
    committe), fixe au tag Git par le nouveau workflow release.yml
    (declenche par push d'un tag vX.Y.Z), "dev" sinon. Affiche en pied de
    page de chaque page du serveur de config embarque.
2026-08-14 docs: traduit tous les fichiers de description en francais
    README racine, NOTICE, firmware/README, hardware/README : le public
    concerne est exclusivement francophone, pas de raison de documenter
    en anglais. LICENSE.md reste en anglais (texte legal officiel de
    CC BY-NC 4.0, ne pas traduire un texte a valeur juridique).
2026-08-17 fix: retire la mention d'exception BREIZHZION dans le resume de licence
2026-08-17 fix: retire toute mention d'aide/service construction-installation de NOTICE.md
2026-08-17 license: remplace CC BY-NC 4.0 par la licence maison BZ-1.1
    Nouvelle licence redigee sur mesure (BREIZHZION Personal Use
    License), beaucoup plus restrictive que CC BY-NC 4.0 : interdiction
    totale de fabriquer pour un tiers meme gratuitement, aucun droit
    accorde aux personnes morales (associations/entreprises), opt-out
    fouille de textes et de donnees / entrainement IA, pas de
    distribution de version modifiee. Seule BREIZHZION (ou un tiers avec
    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
2026-08-22 docs: reference de cablage complete avant schema KiCad
    WIRING.md : nomenclature (BOM), architecture d'alimentation (5V pour
    le MAX98357A directement, pas via la 3,3V regulee de l'ESP32),
    brochage broche par broche identique aux GPIO deja utilises dans
    firmware/src/main.cpp. Pas de fichier .kicad_sch genere a l'aveugle
    (KiCad non installe sur cette machine, format fait pour etre edite
    visuellement) - ce document sert de base fiable pour cabler la
    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
2026-08-22 feat(hardware): premier jet de schema KiCad genere depuis WIRING.md
    generate_schematic.py (bibliotheque kiutils) construit hucheor.kicad_sch
    a partir du brochage documente dans WIRING.md : 4 modules (ESP32,
    CC1101, MAX98357A, DCF77) + haut-parleur + connecteur d'alimentation,
    symboles generiques crees pour l'occasion (pas de symbole officiel
    KiCad pour ces breakouts), connexions par labels de net plutot que
    par fils traces a la main.
    KiCad n'etant pas installe sur cette machine, ce fichier n'a jamais
    ete ouvert dans l'editeur ni passe a l'ERC - seulement relu avec
    succes par kiutils (valide la syntaxe, pas l'exactitude electrique
    ni le rendu visuel). Marque explicitement comme premier jet a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
    [hucheor.kicad_sch]
2026-08-22 fix(hardware): corrige le schema KiCad genere, verifie contre KiCad 10 reel
    KiCad 10 installe : le schema genere par generate_schematic.py
    echouait au chargement (Failed to load schematic, sans detail).
    Cause trouvee par bissection contre un vrai fichier KiCad
    round-trippe par kiutils :
    - Les broches doivent etre portees par des sous-unites imbriquees
    du symbole (unite 0 = dessin, unite 1 = broches), pas directement
    sur le symbole parent - convention utilisee par tous les symboles
    KiCad officiels meme les plus simples (Device:R).
    - La position de chaque propriete (Reference/Value) doit avoir un
    angle explicite (0 si non tourne), sinon KiCad 10 refuse l'instance
    placee alors meme q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
    [hucheor.kicad_sch]
2026-08-30 ci: ajoute le declenchement manuel (workflow_dispatch) en filet de securite
2026-09-05 chore: pose la convention changelog du parc sur ce depot
    CHANGELOG.md au format Keep a Changelog, hooks pre-commit et pre-push dans
    .githooks, et workflow changelog-guard.yml qui rejoue les memes controles en CI
    au moment du tag.
    La convention vaut pour tout depot, sans exception de taille ni d'anciennete.
    Les trois fichiers sont copies tels quels depuis les sources partagees du repo
    admin, sans retouche locale.
2026-09-07 Pose la convention de fins de ligne du parc
    Le bloc run d un workflow GitHub Actions est un script shell execute sur un
    runner Linux : un antislash de continuation suivi d un retour chariot ne
    continue pas la ligne, la commande est coupee en deux, et le message d
    erreur ne parle jamais de fins de ligne.
    Cas reel du 2026-09-07 sur cabanon : un yml recommite en CRLF depuis une
    machine Windows, ou core.autocrlf est actif, a fait echouer le deploiement
    de l API sur un usage: ssh, la destination de la commande ayant disparu
    avec la continuation.
    LF force sur ce qu execute Linux, CRLF sur ce qu execute Windows, et
    text=auto comme filet general. Reference dans
    admin/.claude/gitattributes-parc.
